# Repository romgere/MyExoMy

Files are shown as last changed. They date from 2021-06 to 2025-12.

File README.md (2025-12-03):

# Romgere's Exomy

Remote controlled (Wifi, 4g) 3D printed "Mars rover", inspired by [ESA - ExoMy project](https://github.com/esa-prl/ExoMy/)

"Picture of my Rover (Work in progress)

"Pixture of head of my Rover (Work in progress)

## Freecad parts

All parts are editable in freecad.

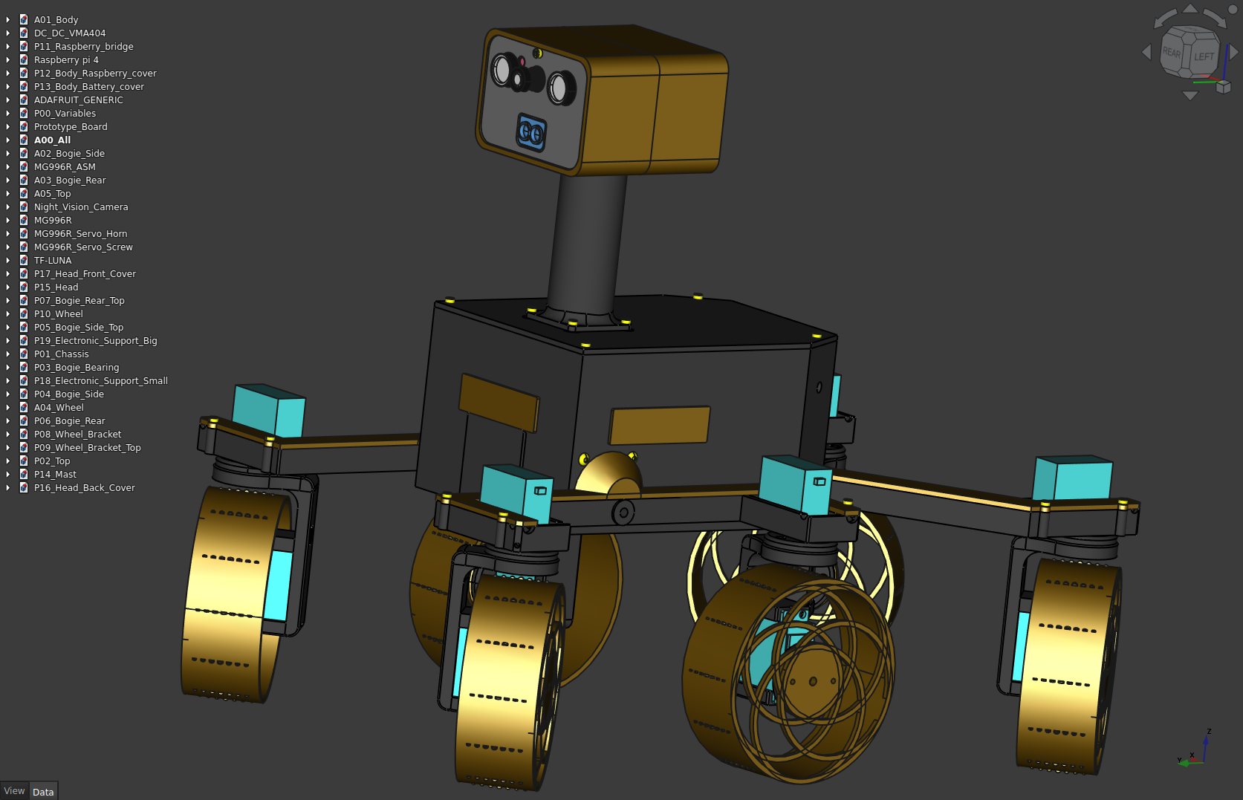
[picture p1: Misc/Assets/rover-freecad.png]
"Rover viewed in freecad


## Control center application

Video stream, live camera settings updates, GPS position, lot of sensors & more.

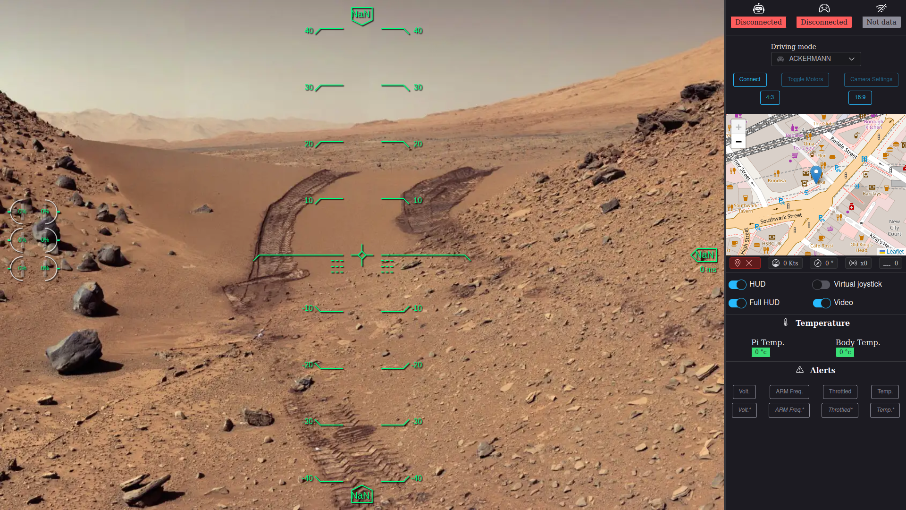
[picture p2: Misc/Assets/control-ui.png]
"The control application


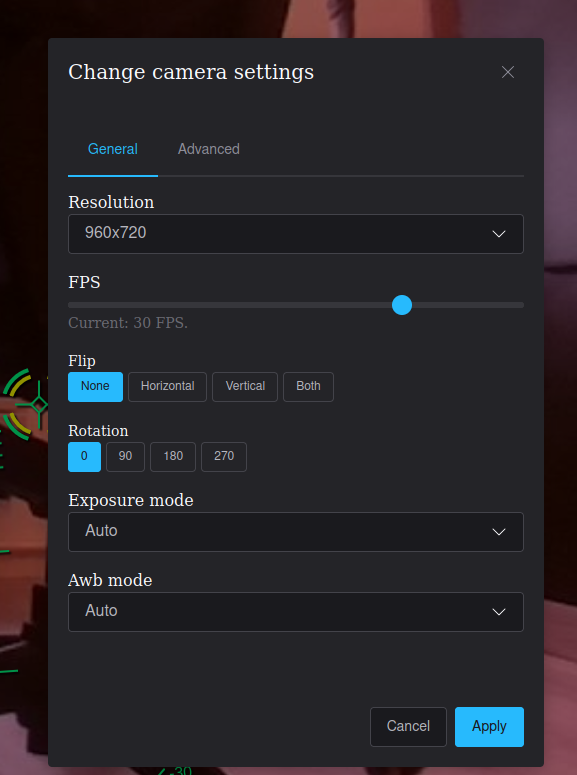
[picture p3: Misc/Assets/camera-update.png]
"The control application, camera update screen


## Configuration application

Easy configuration with the configuration Terminal Uer Interface.

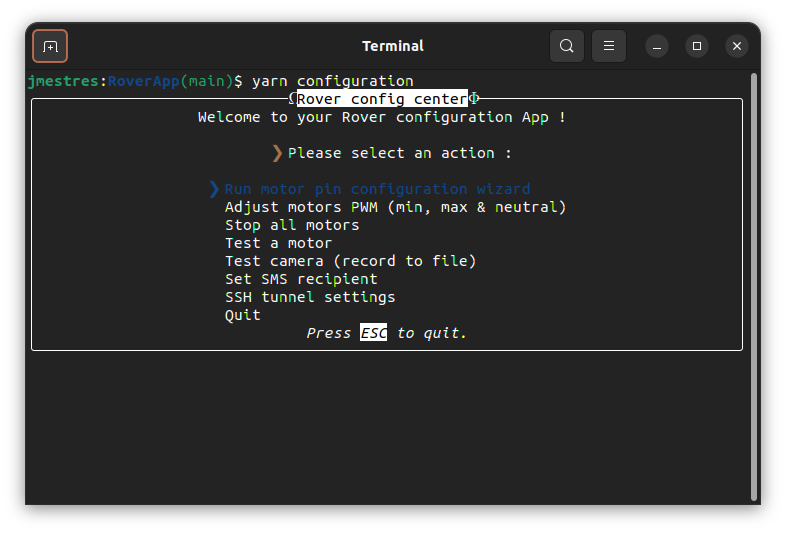
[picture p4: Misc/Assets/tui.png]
"The configuration TUI


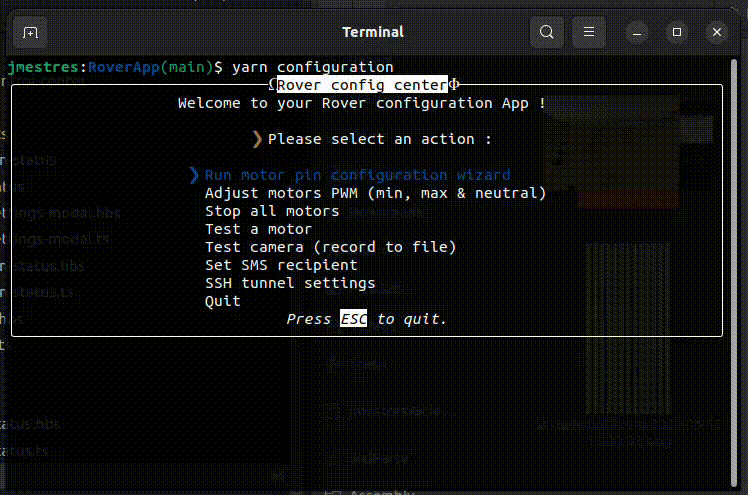
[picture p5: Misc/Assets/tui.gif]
"Video of the configuration application


# What changed

Here is a brief summary of what's change comparing to [original ExoMy project](https://esa-prl.github.io/ExoMy/) :

- Move rover code a mono-repo.
- Code source re-write :
  - Rover: Get rid of ROS & convert rover code into typescript (based on Worker thread for better code isolation & error resilience)
  - Control app: Rewrite with [Ember.js](https://emberjs.com/) framework add "some" feature (Game controller support, new rover feature support, ...)
  - setting scripts has been rewritten in typescript into a TUI app using [ink](https://github.com/vadimdemedes/ink) (based on [React](https://fr.react.dev/))
- Add "some" feature to the rover :
  - Send some measure from raspberry PI (Network quality, vcgencmd infos, ...)
  - Allow live camera settings update
  - Add some HTTP response (ping) to better deal with rover connection
  - add sensor to rover & display values in UI (Lidar, Proximity, Magnetometer, Gyroscope)
  - add a 4g hat to allow controlling the rover from anywhere
  - add support for 4g hat built-in GPS & send live position to control app
  - add support for SMS (some usefull command, like enabling/disabling the SSH tunnel can be performed by sending SMS)
- Native ROS gamepad support has been replaced by using gamepad Api on UI app.
- Improvement of control app UI
- Convert all SolidWorks files to FreeCAD files & do a complete rewrite of the rover parts (see [Mechanical design Readme](./MechanicalDesign/README.md))
  - adapt part to new rover hardware (4g hat & sensor)
  - make it bigger ! ~150% original size
- More to come, see [todo](https://github.com/romgere/MyExoMy/wiki/ToDos)

# Where to start

Take a look to the Wiki : https://github.com/romgere/MyExoMy/wiki

If you start from scratch, you may want to go through the [assembling rover guide](https://github.com/romgere/MyExoMy/wiki/Assembling-the-Rover) or [software installation](https://github.com/romgere/MyExoMy/wiki/Software-installation).

ℹ️ The wiki is still Work In Progress, you can probably make an idea of the work that such project is needed by reading [the original ExoMy wiki](https://github.com/esa-prl/ExoMy/wiki)

# Control App

The control app (as it is on this repository `main` branch) is deployed on netlify. You can use it for your own conveniance if you want :

[https://rover.mestres.fr](https://rover.mestres.fr)
_This can't (yet?) be used for local developpement, Netlify no longer allow HTTP traffic & rover api is HTTPS when serving locally (Not via 4G tunnel)._



# Know issues

- New body height is still a bit small (servo connectors are a bit bended by top)
- 4G on/off commands (SMS) does not work (switching to GSM only make i2c & AT interface somehow exploding)
- body cover need a refactor (ergo are too weak)
- Heading computation is working only when Rover is on plane surface (see packages/RoverApp/src/lib/orientation.ts)

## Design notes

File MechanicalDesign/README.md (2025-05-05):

This folder contains Freecad design of the rover.

All parts has been re-designed. They are mostly simplier than ExoMy one and includes custom modifications (HEad with Night Vision camera + Lidar, larger battery, etc...)

Overall size has been increase by ~150%.

A lot of 3rd party parts (switch, cable, Zip tie ...) has been removed from assembly files.

To open "assembly" files "A2Plus" addon is needed.

## Folder description

- `3rdParty`: Contains 3rd party part (screw, servo, ....).
- `Parts`: Contains parts that has been migrated to freecad
- `Assembly`: Assembly of part (with `A2Plus` addon), this use Freecad & `Converted` parts

## Freecad version

You need freecad V1.0 (or later) to open files.
No external workbenchs are needed to open files, [Fasteners workbench](https://wiki.freecad.org/Fasteners_Workbench/fr) is recommended if you want to edit files.

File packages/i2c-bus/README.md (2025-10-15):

This is a copy of https://github.com/fivdi/i2c-bus with fix for Thread Worker (https://github.com/fivdi/i2c-bus/pull/109)

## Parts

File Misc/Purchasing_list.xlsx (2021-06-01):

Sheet: PI_ExoMy_All_Parts_BoM
Bill of Materials
ITEM NO. | PART NUMBER | Buy | TYPE | CONFIG NAME | Supplier | PURCHASING LINK | Price | QTY. | TOTAL | UPDATE | QTY ORIGINE | QTE LOT | DONE
1 | P01_Chassis | no | 3D | Two Color Print |  |  |  | 1
2 | P02_Drill | no | 3D | Default |  |  |  | 1
3 | P03_Bogie_Bearing | no | 3D | Default |  |  |  | 3
4 | P15_DCDC_Holddown | no | 3D | Default |  |  |  | 2
5 | P04_Battery_Holddown | no | 3D | Default |  |  |  | 1
6 | Parallax-Servo | yes | servo | Steering Modded | chine | https://fr.aliexpress.com/item/1005002512906278.html | 16.46 € | 2 | 32.92 € | done |  | 5 | Y
10 | Parallax-Servo | yes | servo | Continuous | chine | https://fr.aliexpress.com/item/1005002512906278.html | 18.23 € | 2 | 36.46 € | done |  | 5 | Y
7 | Parallax-Servo-Horn | no | N/A | Default |  | come with motor |  | 12
8 | Parallax-Servo-Screw | no | N/A | Default |  | come with motor |  | 12
9 | P28_Wheel_Bracket_Split | no | 3D | Left Wiring |  |  |  | 3
14 | Button Head M4x10 | yes | screw | Button Head M4x10 | chine | https://fr.aliexpress.com/item/33047947128.html | 1.41 | 5 | 7.05 € | done | 54 |  | Y
15 | SCB3_8 | yes | screw | Socket Head M3x8 | chine | https://fr.aliexpress.com/item/33046502668.html | 0.92 | 2 | 1.84 € | done | 51 |  | Y
11 | P29_Wheel_Bracket_Fixing_Plate | no | 3D | Default |  |  |  | 6
12 | P30_Wheel | no | 3D | Default |  |  |  | 6
13 | P32_Wheel_Fixing_Plate_U_Shape | no | 3D | Default |  |  |  | 6
19 | Button Head M4x16 | yes | screw | Button Head M4x16 | chine | https://fr.aliexpress.com/item/33047947128.html | 1.49 | 1 | 1.49 € | done | 6 |  | Y
20 | SFB3_6 | yes | screw | Countersink Head M3x6 | chine | https://fr.aliexpress.com/item/33049019185.html | 1.03 | 1 | 1.03 € | done | 11 |  | Y
16 | P28_Wheel_Bracket_Split | no | 3D | Right Wiring |  |  |  | 3
17 | P19_Bogie | no | 3D | Two Color Print |  |  |  | 1
18 | P17_Bogie_Cable_Cover | no | 3D | Rear Cover |  |  |  | 1
21 | Button Head M5x30 | yes | screw | Button Head M5x30 | chine | https://fr.aliexpress.com/item/33047947128.html | 1.63 | 1 | 1.63 € | done | 3 |  | Y
23 | Servo Extension Cable (25cm) | yes | cable | 25 | chine | https://fr.aliexpress.com/item/4001293611208.html | 4.48 € | 2 | 8.96 € | done | 12 |  | Y
38B |  | yes | electronics | D | chine | https://fr.aliexpress.com/item/1005001870492327.html | 8.81 € | 1 | 8.81 € | done |  |  | Y
22 | Zip_Tie | no | 3D | Bogie |  |  |  | 6
38 | Raspberry Pi Camera V2 | yes | electronics | Default | chine | https://fr.aliexpress.com/item/4001162865845.html | 2.13 € | 1 | 2.13 € | done | 1 |  | Y
40 | SCB2_5 | yes | screw | Socket Head M2x5 | chine | https://fr.aliexpress.com/item/33046502668.html | 0.99 | 1 | 0.99 € | done | 4 |  | Y
45 | Adafruit PWM Servo HAT | yes | electronics | Default | chine | https://fr.aliexpress.com/item/1005001936050289.html | 9.74 € | 1 | 9.74 € | done |  |  | Y
26 | P19_Bogie | no | 3D | Side |  |  |  | 2
27 | P17_Bogie_Cable_Cover | no | 3D | Two Color Print |  |  |  | 2
28 | Zip_Tie | no | 3D | Body |  |  |  | 7
29 | P13_Port_Cover | no | 3D | Default |  |  |  | 1
30 | P14_Raspi_Holder | no | 3D | Default |  |  |  | 2
31 | P11_Top | no | 3D | Default |  |  |  | 1
32 | P20_Head | no | 3D | Default |  |  |  | 1
33 | P22_Eye_White | no | 3D | Default |  |  |  | 2
34 | P23_Eye_Pupil | no | 3D | Default |  |  |  | 2
35 | P24_Mouth_Latch | no | 3D | Default |  |  |  | 1
36 | P25_Mouth | no | 3D | Grin |  |  |  | 1
37 | P33_Cam_Holder_Flat | no | 3D | Default |  |  |  | 1
48 | DC_DC_VMA404 | yes | electronics | Default | chine | https://fr.aliexpress.com/item/4000067511936.html | 1.02 € | 2 | 2.04 € | done |  |  | Y
52 | Battery Alarm | yes | electronics | Default | chine | https://fr.aliexpress.com/item/389380569.html | 1.81 € | 1 | 1.81 € | done |  |  | Y
39 | P26_Hat | no | 3D | Eyebrows |  |  |  | 1
59 | SCB3_20 | yes | screw | Socket Head M3x20 | chine | https://fr.aliexpress.com/item/33046502668.html | 1.92 | 1 | 1.92 € | done | 4 |  | Y
41 | P21_Mast | no | 3D | Default |  |  |  | 1
42 | P12_Solar_Panel | no | 3D | Right |  |  |  | 1
43 | P12_Solar_Panel | no | 3D | Left |  |  |  | 1
60 | M3-Insert | yes | screw | Brass Insert M3 | chine | https://fr.aliexpress.com/item/1005002432903363.html | 11.57 € | 1 | 11.57 € | done | 4 |  | Y
64 | Shrink_Tube | yes | heatshrink | Default | chine | https://fr.aliexpress.com/item/4001223956064.html? | 2.35 | 1 | 2.35 € | done |  |  | Y
44 | Raspberry Pi 4 Model B | yes | electronics | Default | Conrad | https://www.conrad.nl/p/raspberry-pi-4-b-2-gb-4-x-15-ghz-raspberry-pi-2138863 | 58.00 € | 0 | 0.00 € | nope
46 | USB-C Plug | yes | cable | Default | Conrad | https://www.conrad.nl/p/joy-it-k-1473-power-cable-raspberry-pi-arduino-banana-pi-cubieboard-1x-usb-c-plug-1x-sony-xperia-1-m-black-2159636 | 3.40 € | 0 | 0.00 € | nope
47 | USB-Dongle | yes | controller | GamePad | Conrad | https://www.conrad.nl/p/logitech-gaming-f710-wireless-controller-gamepad-pc-silver-519585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 | 47.00 € | 0 | 0.00 € | nope
49 | Conrad LiPo 3S 3000mAh - 1344138 | yes | electronics | Default | Conrad | https://www.conrad.nl/p/conrad-energy-lipo-accupack-111-v-3000-mah-aantal-cellen-3-20-c-softcase-xt60-1344138 | 30.00 € | 0 | 0.00 € | nope
50 | Toggle Switch | yes | electronics | Default | Conrad | https://www.conrad.nl/p/apem-5246a-52460003-tuimelschakelaar-250-vac-3-a-2x-aanaan-continu-1-stuks-700192 | 2.40 € | 0 | 0.00 € | nope
51 | Rocker Switch | yes | electronics | Default | chine | https://fr.aliexpress.com/item/1005002667205988.html | 1.05 € | 1 | 1.05 € | done |  |  | Y
61 | M2_5x11 | yes | screw | Standoff M2.5x11 | chine | https://fr.aliexpress.com/item/32866710046.html | 4.11 | 1 | 4.11 € | done | 3 |  | Y
53 | Long_Camera_Cabel | yes | cable | Default | chine | https://fr.aliexpress.com/item/32955287044.html | 6.49 € | 1 | 6.49 € | done
54 | Power_Switch_to_DCDC_Cable | no | N/A | Default |  |  |  | 1
55 | XT-60_Macho Male Pins | yes | cable | Default | chine | https://fr.aliexpress.com/item/1005002368630646.html | 1.48 € | 1 | 1.48 € | done
56 | DCDC_to_PWM_Board_Cable | no | N/A | Default |  |  |  | 1
6 | Parallax-Servo | yes | servo | Steering Modded | mouser | https://www.mouser.fr/ProductDetail/Parallax/900-00005?qs=b0EQgHdmdblOQWsNGSCRcw== | 12.07 € | 0 | 0.00 € | nope | 6
10 | Parallax-Servo | yes | servo | Continuous | mouser | https://www.mouser.fr/ProductDetail/Parallax/900-00008?qs=sGAEpiMZZMsqIr59i2oRcksQ7aZ82z2Ufa12wMSCHww%3D | 13.86 € | 0 | 0.00 € | nope | 6
57 | Switches_to_DCDC_Cable | yes | cable | Default | Conrad | https://www.conrad.fr/p/fil-de-cablage-alphawire-3053-vi001-1-x-050-mm-violet-marchandise-vendue-au-metre-1368718 | 0.42 € | 1 | 0.42 € | done
58 | Battery_to_Switch_Cable | yes | electronics | Default | Conrad | https://www.conrad.fr/p/fil-de-cablage-alphawire-3057-sl001-1-x-131-mm-ardoise-marchandise-vendue-au-metre-1368731 | 0.53 € | 1 | 0.53 € | done
62 | Phillips Head M2.5x6 | yes | screw | Phillips Head M2.5x6 |  |  |  |  | 0.00 € | nope | 3 | 100
24 | Servo Extension Cable | yes
25 | Servo Extension Cable | yes
63 |  |  |  |  |  |  |  |  |  | nope
 |  |  |  |  |  | Total | 146.82

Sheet: Feuil1
M4 x 10
M4 x 16
M3 x 8
M3 x 6
M3 x 20
M5 x 30
module GSM compatible : | https://fr.aliexpress.com/item/1005001744059621.html
 | https://www.raspberrypi.org/forums/viewtopic.php?t=224355
 | "Be aware that SIM7600E has "-H" and "-T" chip. DON'T buy "-T" chip, it is for China."
 |  | https://fr.aliexpress.com/item/33049019185.html | flat
 |  | https://fr.aliexpress.com/item/33047947128.html | round
 |  | https://fr.aliexpress.com/item/33046502668.html | socket

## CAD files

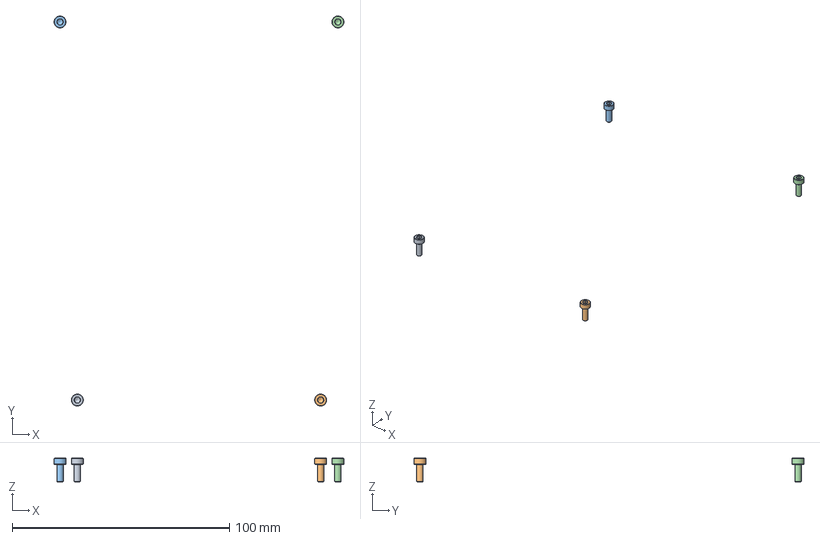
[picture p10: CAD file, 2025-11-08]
MechanicalDesign/Assembly/A00_All.FCStd
133.4 x 179.5 x 11.0 mm
M3x8-Screw085 x 2
M3x8-Screw086 x 2
M3x8-Screw087 x 2
M3x8-Screw088 x 2

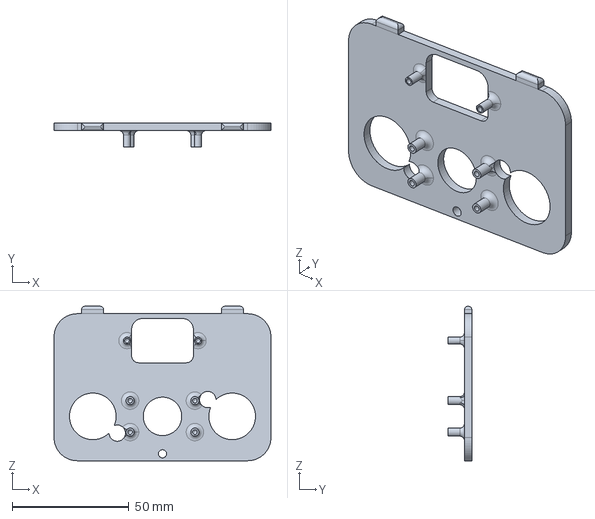
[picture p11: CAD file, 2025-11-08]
MechanicalDesign/Parts/P17_Head_Front_Cover.FCStd
93.1 x 10.2 x 66.3 mm

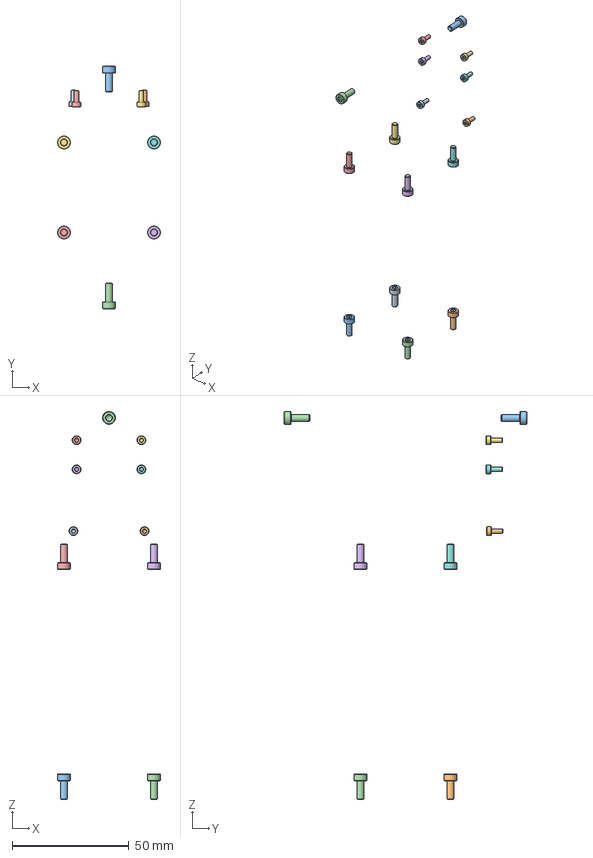
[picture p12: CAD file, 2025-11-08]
MechanicalDesign/Assembly/A05_Top.FCStd
44.1 x 104.0 x 166.3 mm
M3x8-Screw x 2
M3x8-Screw030 x 2
M3x8-Screw031 x 2
M3x8-Screw032 x 2
M3x8-Screw033 x 2
M3x8-Screw034 x 2
M3x8-Screw035 x 2
M3x8-Screw036 x 2
M2x5-Screw x 2
M2x5-Screw042 x 2
M3x8-Screw038 x 2
M3x8-Screw037 x 2
M2x5-Screw043 x 2
M2x5-Screw039 x 2
M2x5-Screw044 x 2
M2x5-Screw041 x 2

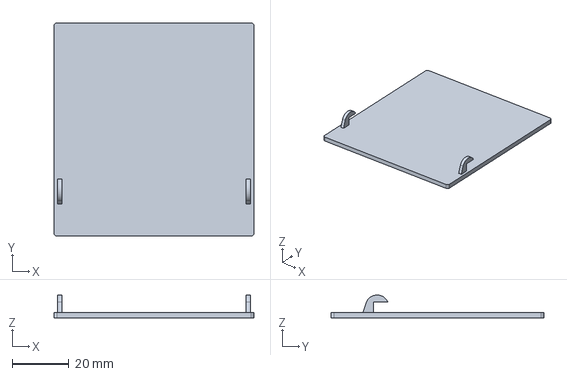
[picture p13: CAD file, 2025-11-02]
MechanicalDesign/Parts/P13_Body_Battery_cover.FCStd
70.4 x 75.0 x 8.08 mm

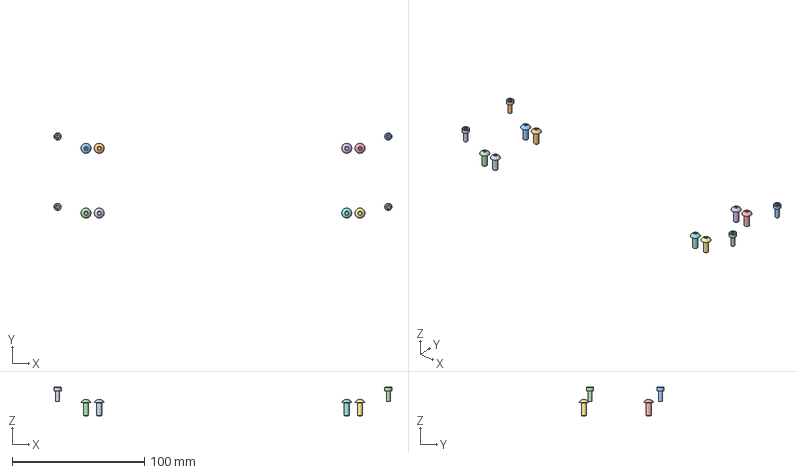
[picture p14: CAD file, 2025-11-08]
MechanicalDesign/Assembly/A02_Bogie_Side.FCStd
255.5 x 64.4 x 21.7 mm
M3x8-Screw x 2
M3x8-Screw020 x 2
M3x8-Screw021 x 2
M3x8-Screw022 x 2
M4x10-Screw023 x 2
M4x10-Screw x 2
M4x10-Screw028 x 2
M4x10-Screw025 x 2
M4x10-Screw027 x 2
M4x10-Screw026 x 2
M4x10-Screw029 x 2
M4x10-Screw024 x 2

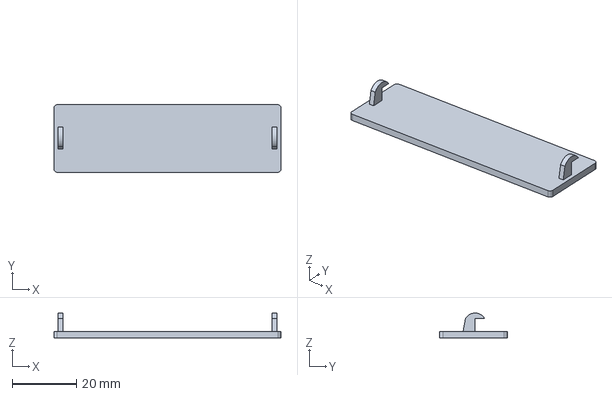
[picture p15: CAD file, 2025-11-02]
MechanicalDesign/Parts/P12_Body_Raspberry_cover.FCStd
70.4 x 21.0 x 7.72 mm

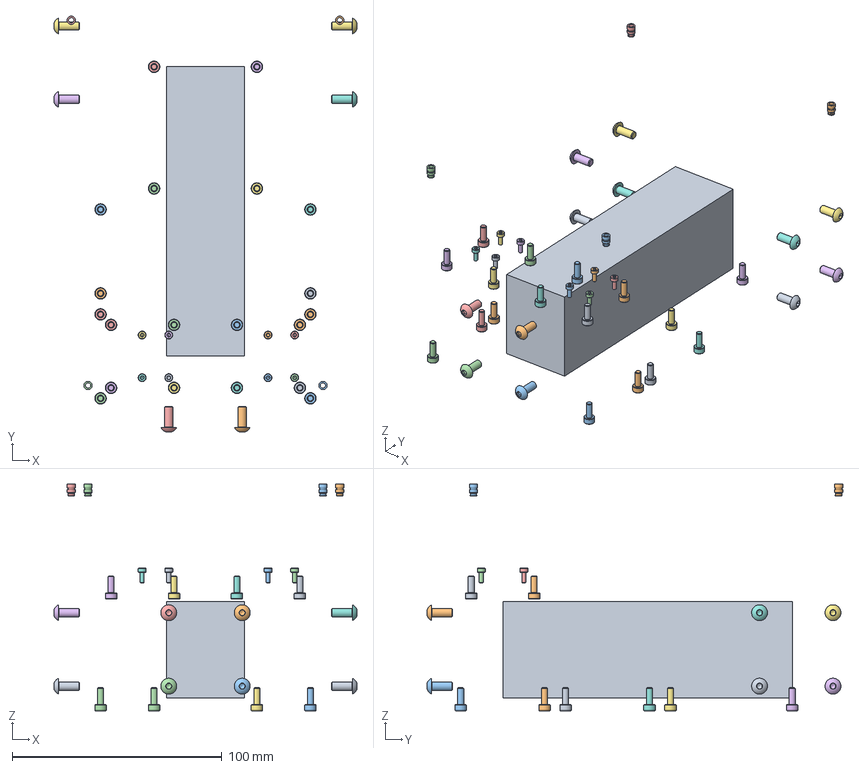
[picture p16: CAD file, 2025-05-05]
MechanicalDesign/Assembly/A01_Body.FCStd
144.4 x 198.2 x 108.0 mm
Battery x 2
M3x5.74-Insert x 2
M3x5.74-Insert047 x 2
M3x5.74-Insert048 x 2
M3x5.74-Insert049 x 2
M4x10-Screw x 2
M4x10-Screw081 x 2
M4x10-Screw082 x 2
M4x10-Screw083 x 2
M4x10-Screw084 x 2
M4x10-Screw085 x 2
M4x10-Screw086 x 2
M4x10-Screw087 x 2
M4x10-Screw088 x 2
M4x10-Screw089 x 2
M4x10-Screw090 x 2
M4x10-Screw091 x 2
M2x5-Screw x 2
M2x5-Screw001 x 2
M2x5-Screw002 x 2
M2x5-Screw003 x 2
M2x5-Screw004 x 2
M2x5-Screw005 x 2
M2x5-Screw006 x 2
M2x5-Screw007 x 2
M3x8-Screw x 2
M3x8-Screw031 x 2
M3x8-Screw032 x 2
M3x8-Screw033 x 2
M3x8-Screw034 x 2
M3x8-Screw035 x 2
M3x8-Screw036 x 2
M3x8-Screw037 x 2
M3x8-Screw046 x 2
M3x8-Screw047 x 2
M3x8-Screw048 x 2
M3x8-Screw049 x 2
M3x8-Screw050 x 2
M3x8-Screw051 x 2
M3x8-Screw052 x 2
M3x8-Screw053 x 2
M3x8-Screw068
M3x8-Screw069
M3x8-Screw070
M3x8-Screw071

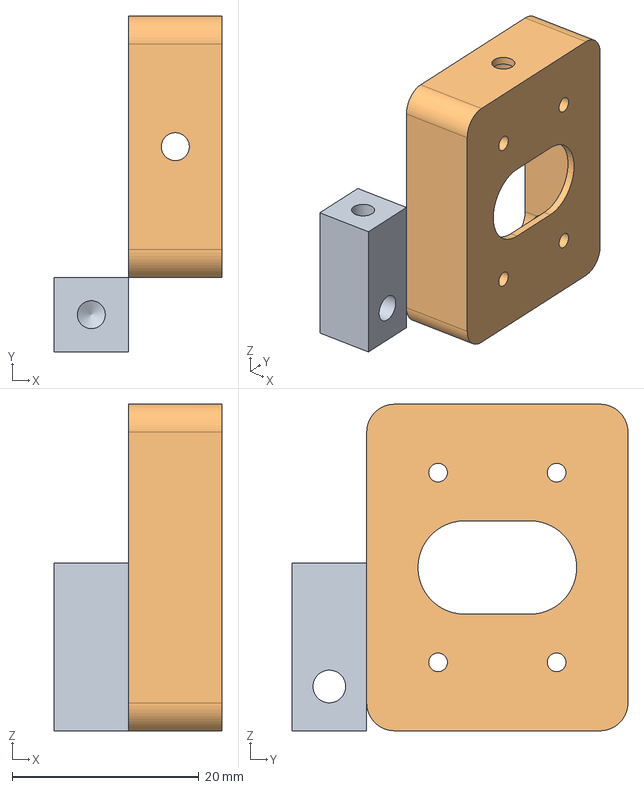
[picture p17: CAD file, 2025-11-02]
MechanicalDesign/Parts/P22_Proximity_Sensor_Holder.FCStd
18.0 x 36.0 x 35.0 mm
P22_Proximity_Sensor_Holder_P1
P22_Proximity_Sensor_Holder_P2

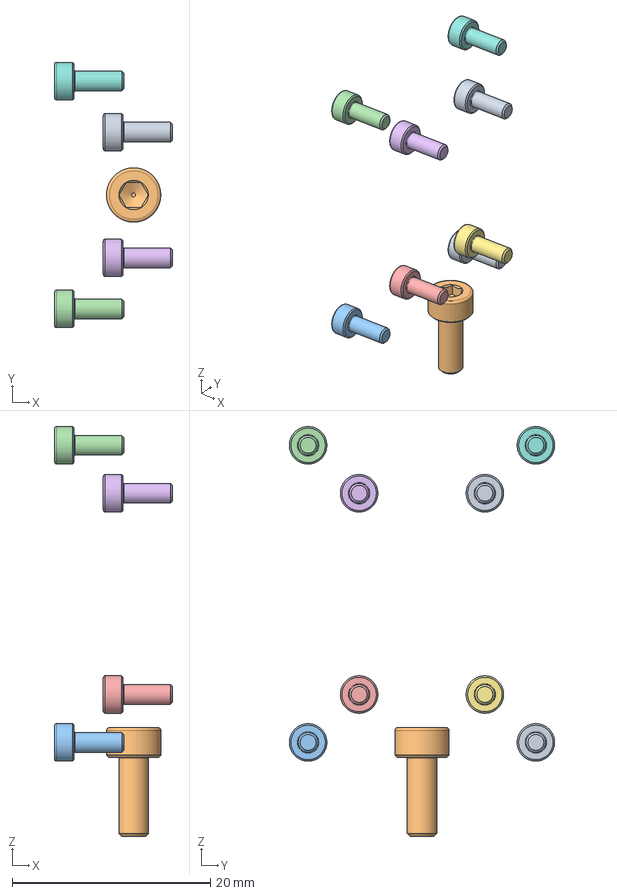
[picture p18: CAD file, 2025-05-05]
MechanicalDesign/Assembly/A06_Proximity_Sensor.FCStd
11.9 x 26.8 x 41.4 mm
M2x5-Screw022 x 2
M3x8-Screw x 2
M2x5-Screw023 x 2
M2x5-Screw024 x 2
M2x5-Screw025 x 2
M2x5-Screw026 x 2
M2x5-Screw027 x 2
M2x5-Screw x 2
M2x5-Screw028 x 2

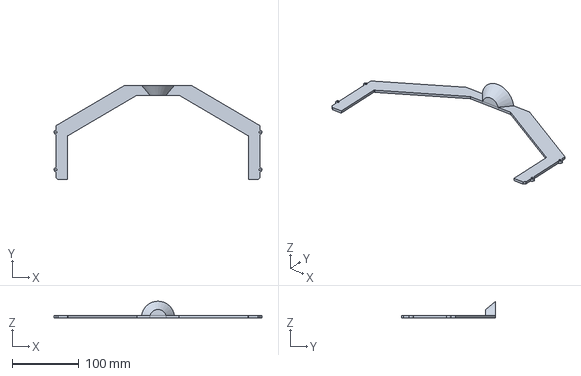
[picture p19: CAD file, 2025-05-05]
MechanicalDesign/Parts/P07_Bogie_Rear_Top.FCStd
312.8 x 142.0 x 25.0 mm

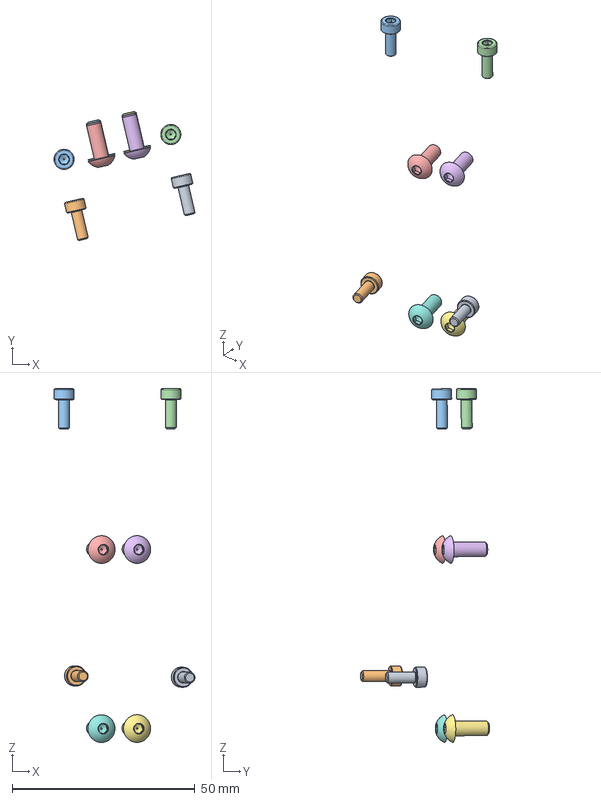
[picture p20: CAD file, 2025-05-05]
MechanicalDesign/Assembly/A04_Wheel.FCStd
38.6 x 35.3 x 96.9 mm
M3x8-Screw x 2
M3x8-Screw007 x 2
M3x8-Screw008 x 2
M3x8-Screw009 x 2
M4x10-Screw x 2
M4x10-Screw004 x 2
M4x10-Screw005 x 2
M4x10-Screw006 x 2

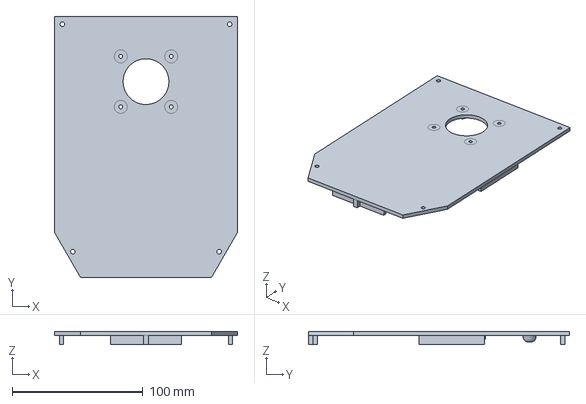
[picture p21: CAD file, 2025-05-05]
MechanicalDesign/Parts/P02_Top.FCStd
140.0 x 200.0 x 10.2 mm

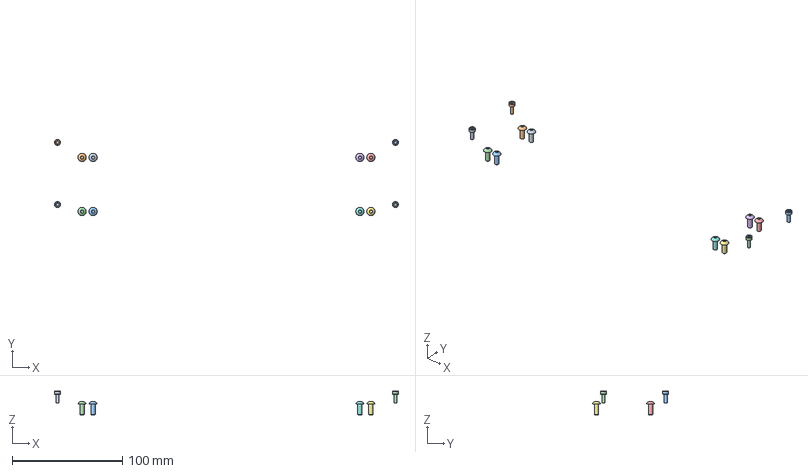
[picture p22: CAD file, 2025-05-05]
MechanicalDesign/Assembly/A03_Bogie_Rear.FCStd
311.9 x 69.2 x 21.7 mm
M3x8-Screw x 2
M3x8-Screw016 x 2
M3x8-Screw017 x 2
M3x8-Screw018 x 2
M4x10-Screw x 2
M4x10-Screw032 x 2
M4x10-Screw033 x 2
M4x10-Screw034 x 2
M4x10-Screw035 x 2
M4x10-Screw036 x 2
M4x10-Screw037 x 2
M4x10-Screw038 x 2

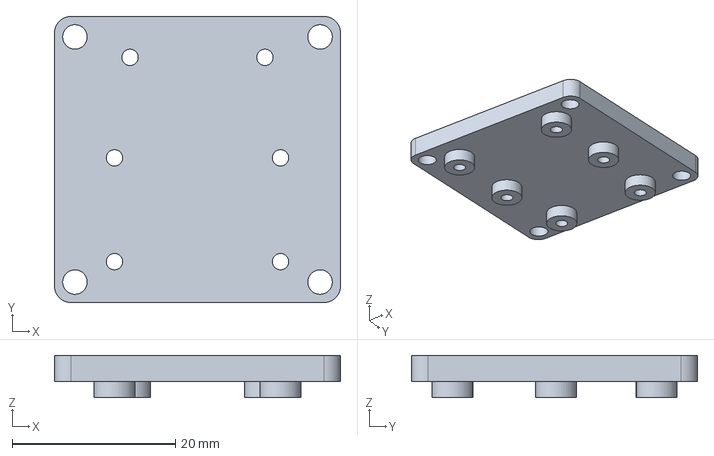
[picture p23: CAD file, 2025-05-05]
MechanicalDesign/Parts/P18_Electronic_Support_Small.FCStd
35.0 x 35.0 x 5.20 mm

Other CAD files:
MechanicalDesign/Parts/P11_Raspberry_bridge.FCStd
MechanicalDesign/Parts/P09_Wheel_Bracket_Top.FCStd
MechanicalDesign/Parts/P15_Head.FCStd
MechanicalDesign/Parts/P14_Mast.FCStd
MechanicalDesign/Parts/P00_Variables.FCStd
MechanicalDesign/Parts/P01_Chassis.FCStd
MechanicalDesign/Parts/P03_Bogie_Bearing.FCStd
MechanicalDesign/Parts/P04_Bogie_Side.FCStd
MechanicalDesign/Parts/P05_Bogie_Side_Top.FCStd
MechanicalDesign/Parts/P06_Bogie_Rear.FCStd
MechanicalDesign/Parts/P08_Wheel_Bracket.FCStd
MechanicalDesign/Parts/P16_Head_Back_Cover.FCStd
MechanicalDesign/Parts/P19_Electronic_Support_Big.FCStd
MechanicalDesign/Parts/P20_Electronic_Support_Big_2.FCStd
MechanicalDesign/Parts/P21_Cable_Protection.FCStd

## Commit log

2021-06-01 refactor folder & put some information into readme
    [A02_Chassis.FCStd, A04_Wheel_Assembly_Left_Wiring.FCStd, A04_Wheel_Assembly_Right_Wiring.FCStd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]
2021-06-08 Update drive motor neutral script to allow custom neutral value in conf
2021-06-08 create cheap servo part
    [ASM-MG996R.FCStd, MG996R.FCStd, test_servo_mounting-Cut001.stl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]
2021-06-08 update P28 left & right + A04 left & right
    [A04_Wheel_Assembly_Left_Wiring.FCStd, A04_Wheel_Assembly_Right_Wiring.FCStd, P28_Wheel_Bracket_Split_Left_Wiring.fcstd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]
2021-06-08 tmp P19, raf: A04? + cover ?
    [P19_Bogie_Side.fcstd, P19_Bogie_Two_Color_Print.fcstd]
2021-06-11 update P28 for deeper servo hat
    [P28_Wheel_Bracket_Split_Left_Wiring.fcstd, P28_Wheel_Bracket_Split_Right_Wiring.fcstd]
2021-06-11 update P30 for deeper heap servo hat
    [P30_Wheel.fcstd]
2021-06-11 remove useless legacy servo & update new one
    [ASM-MG996R.FCStd, ASM_Parallax_Servo_Continuous.FCStd, ASM_Parallax_Servo_Steering_Modded.FCStd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]
2021-06-11 update A04 with new servo & P30 + P28 part
    [A04_Wheel_Assembly_Left_Wiring.FCStd, A04_Wheel_Assembly_Right_Wiring.FCStd]
2021-06-11 put some colors
    [A02_Chassis.FCStd, A04_Wheel_Assembly_Left_Wiring.FCStd, A04_Wheel_Assembly_Right_Wiring.FCStd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]
2021-06-23 add neutral,min&max for all servo & handle it in conf & motor node file
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2021-06-23 add a workarround to prevent cheap servo issues
2023-08-15 fix wheel iteration
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2023-08-18 feat: prevent control app to be part of mono repo when running on raspberry/docker
2023-08-18 feat: refactor socket server to proxy all event to broadcaster & allow hot camera settings reloading
2023-08-18 feat: secure events that can be received by socket
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2023-08-21 fix: ensure camera listener is cleaned when camera is stop
2023-08-22 prepare some sensor value & put them into UI
2023-08-22 implement pi-sensor service & handle event on UI
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2023-08-23 fix config motor script & update conf
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2023-08-24 bind gyroscropt data to hud & add some UI options
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2023-08-25 clean code & send magneto data in externalSensor event
2023-08-25 refactor gyro sensor to send raw data & compute rover orientation in ember app
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2023-08-29 refactor I2CRegister to allow "random" size + update lidar sensor according
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2023-08-31 add i2c repartitor schema
    [i2x-repartition-board.fzz]
2023-08-31 feat: add i2s multiplexer & add 4 proximity sensors
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2025-03-20 Full rewrite part 1 (body & top) + reorg part folder
    [A01_Body.FCStd, A02_Chassis.FCStd, A04_Wheel_Assembly_Left_Wiring.FCStd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]
2025-03-21 Part 2 - Bogie bearing, bogie side & bogie side top + assemblies
    [A00_All.FCStd, A01_Body.FCStd, A02_Bogie_Side.FCStd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]
2025-03-28 Part 3 - Bogie rear & bogie rear top + assemblies
    [A00_All.FCStd, A01_Body.FCStd, A02_Bogie_Side.FCStd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]
2025-03-28 Part 4 - Wheel bracket & wheel bracket top + assemblies
    [A00_All.FCStd, A01_Body.FCStd, A02_Bogie_Side.FCStd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]
2025-03-29 Part 5 - Wheel + assemblies
    [A00_All.FCStd, A01_Body.FCStd, A02_Bogie_Side.FCStd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]
2025-03-31 Part 6 - Update servo horn dimension + assemblies
    [A00_All.FCStd, A04_Wheel.FCStd, P08_Wheel_Bracket.FCStd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]
2025-04-01 Part 7 - Update body, increase wheel & wheel bracket size, create raspbery bridge & udpate assemblies
    [A00_All.FCStd, A01_Body.FCStd, A04_Wheel.FCStd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]
2025-04-03 Udpate assemblies
    [A00_All.FCStd, A01_Body.FCStd, A02_Bogie_Side.FCStd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]
2025-04-03 Part 8 - Update body with 2 x raspberry pockets + create covers + update assemblies
    [A00_All.FCStd, A01_Body.FCStd, A02_Bogie_Side.FCStd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]
2025-04-03 Part 9 - Create Mast, Head & front/rear covers + Assemblies
    [A00_All.FCStd, A01_Body.FCStd, A02_Bogie_Side.FCStd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]
2025-04-03 Clean-up MechanicalDesign folder & update readme
    [P01_Chassis_Two_Color_Print.fcstd, P02_Drill.fcstd, P03_Bogie_Bearing.fcstd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]
2025-04-04 Small fixes & create electonics supports
    Fixes :
    - body: holes size
    - head: add chamfer on screw supports
    - head: fix holes size
    [A01_Body.FCStd, A05_Top.FCStd, P00_Variables.FCStd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]
2025-04-04 Add some colors ^
    [A00_All.FCStd, A01_Body.FCStd, A02_Bogie_Side.FCStd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]
2025-04-04 Remove old assemblies
    [A04_Wheel_Assembly_Left_Wiring.FCStd, A04_Wheel_Assembly_Right_Wiring.FCStd, A06_Head.FCStd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]
2025-04-04 Fix wheel servo screw hole size
    [A00_All.FCStd, A01_Body.FCStd, A04_Wheel.FCStd]
2025-04-04 Reduce wheel bracket top height
    [A00_All.FCStd, A01_Body.FCStd, A04_Wheel.FCStd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]
2025-04-05 Small fixes on wheel bracket
    [P08_Wheel_Bracket.FCStd]
2025-04-07 Fix / create electronic support
    P11: fix hole size on raspberry bridge + add battery ergo
    P18: fix hole distance
    P19: increase hole distance
    P20 : create a new electronics support to stop battery &
    [A01_Body.FCStd, P11_Raspberry_bridge.FCStd, P18_Electronic_Support_Small.FCStd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]
2025-04-09 Fix covers, chage ergo size/shape
    [P12_Body_Raspberry_cover.FCStd, P13_Body_Battery_cover.FCStd]
2025-04-09 Fix sensor hole position
    [P04_Bogie_Side.FCStd]
2025-04-10 rework bogies servo pocket size & shape
    - Add hole & reduce wall size to allow wheel bearing to be mounted/screwed
    - Add ziptie holes
    [A02_Bogie_Side.FCStd, A03_Bogie_Rear.FCStd, P00_Variables.FCStd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]
2025-04-11 update assembly
    [A00_All.FCStd, A01_Body.FCStd, A04_Wheel.FCStd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]
2025-04-14 create a cable protection
    [P21_Cable_Protection.FCStd]
2025-04-24 Create proximity holder & assembly
    [A06_Proximity_Sensor.FCStd, P22_Proximity_Sensor_Holder.FCStd]
2025-10-14 chore: improve external sensor read & reduce event cadence
2025-10-15 chore: create a local fork of i2c-bus to allow thread worker
2025-10-15 chore: use worker threads to isolate & run services
2025-10-15 chore: update sensor timing on rover & "smooth" setting on UI to improve behavior
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2025-10-15 chore: fix camera default settings in UI
2025-10-15 chore: add button to reset to default in camera settings modal
2025-10-20 chore: make config script able to run a mocked verion of pca 9685 driver
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2025-10-25 chore: enable ink text input for camera settings config script
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2025-10-26 fix: revert previous improvement as proximity sensor read is wrong.
2025-11-02 Fix proximity sensor case
    [P22_Proximity_Sensor_Holder.FCStd]
2025-11-02 Update Battery cover. Make single cover for rapsberry & battery on rover front
    [P12_Body_Raspberry_cover.FCStd, P13_Body_Battery_cover.FCStd]
2025-11-02 fix: fix I2C registre MSB implementation
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2025-11-07 feat: make a custom implementation of pi-camera-connect compatible with new rapsberry pi video stack
2025-11-08 chore: update head front cover for new camera
    [A00_All.FCStd, A02_Bogie_Side.FCStd, A05_Top.FCStd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]
2025-11-08 revamp hariron calibration script & fix heading & orientation "smoothing"
2025-12-03 Fix read values on gyro
2026-10-29 fix: build Cloudflare worker from repo root with Node 20
    Workers Builds runs from the repo root (yarn workspace @robot/control-center
    build), so wrangler.jsonc moves to the root and points at
    packages/ControlCenter/dist. Its name now matches the existing worker
    (myexomy). Pin Node 20 (as in CI) since the default Node 24 fails to compile
    the native i2c-bus/epoll modules during yarn install.
    Claude-Session: https://claude.ai/code/session_01ERJoZzBw6vChT3hp8EypKx
